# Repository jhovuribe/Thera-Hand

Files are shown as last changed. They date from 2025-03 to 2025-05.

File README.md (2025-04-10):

# Thera-Hand

## Team Members:
Jhovanny
Aliyaa
Akash
Caden
Andy
Ethan

## Need Statement
People with hand disabilities and injuries face challenges in attending
physical therapy sessions multiple times a week during their recovery period due to the demands of their lives. This will slow or reverse recovery
progress if sessions are insufficient or missed.

## Goal Statement
We aim to address this by providing a device that allows clients to perform their exercises at home, reducing in-person visits. Our goal is to make rehabilitation more convenient, accessible and efficient, allowing
clients to have more control over their recovery.

## Design Objective
We aim to reduce physical therapy visits by up to 50%, subsequently reducing insurance costs.

Team Progress Site:
https://instinctive-raft-cfa.notion.site/Project-Hub-1837bff9001a8023af18f2008f6e7fae

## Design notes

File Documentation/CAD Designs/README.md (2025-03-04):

This folder contains CAD Designs, rough drafts of certain components that will be made to accomodate our final design. Akash Srinivasan

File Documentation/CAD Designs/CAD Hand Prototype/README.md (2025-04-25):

These CAD files represent the functional prototype we will be presenting and showcasing but in CAD. We intend on using this model as a baseline for our design

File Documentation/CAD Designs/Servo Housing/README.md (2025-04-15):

This Folder contains the STEP files and CAD designs for the servo housing component included in our design

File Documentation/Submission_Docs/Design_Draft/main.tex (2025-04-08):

\documentclass{article}
\usepackage{hyperref}
\usepackage{longtable}
\usepackage{graphicx}
\usepackage{booktabs}
\usepackage{pdfpages}
\usepackage{float}
\usepackage{ragged2e}
\usepackage{placeins}
\usepackage{caption}
\usepackage{array}
\usepackage{enumitem}
\usepackage{titlesec}
\usepackage{siunitx}
\setcounter{secnumdepth}{4}
\titleformat{\paragraph}
{\normalfont\normalsize\bfseries}{\theparagraph}{1em}{}
\titlespacing*{\paragraph}
{0pt}{3.25ex plus 1ex minus .2ex}{1.5ex plus .2ex}
\title{draft_design}
\author{Caden Roberts}
\date{March 2025}

\begin{document}
\begin{titlepage}
    \centering
    \vspace*{4cm}

    % Main project title
    {\Huge \bfseries Thera-Hand\par}
    \vspace{0.75cm}

    % Subtitle
    {\LARGE \bfseries Draft Design Document\par}
    \vspace{1.5cm}

    % Course information
    {\Large CSE 123A\par}
    \vspace{0.5cm}

    % Date
    {\Large March 11, 2025\par}
    \vfill

    % Team Members
    {\large
        Akash Srinivasan \par
        Caden Roberts \par
        Jhovanny Uribe \par
        Andy Vo \par
        Ethan Cesario \par
        Aliyaa Islam \par
    }

    \vspace{1cm}
    % GitHub Link
    \href{https://github.com/jhovuribe/Physical-Therapy-Hand-Rehabilitation-Device/}{\LARGE \bfseries GitHub Repository}
    
\end{titlepage}

\section{Executive Summary}
This document details the design, development, and analysis of a hand rehabilitation device to be used in conjunction with physical therapy, titled "Thera-Hand," to improve patient adherence to therapy routines through remote monitoring and automation. The project follows a structured approach, integrating ethical considerations, user-centered design, and engineering analysis.

\section{Ethics Statement}
We reference: \href{https://www.apta.org/siteassets/pdfs/policies/codeofethicshods06-20-28-25.pdf}{The Code of Ethics for the Physical Therapist} \\ \\ 
With our physical therapy hand device we aim to address treatment for those who would
benefit from remote commitment to treatment[2][3], adapting to modern trends to benefit
therapists[6] and clients[7] and serving those without consistent access to therapy[8].
\begin{itemize}
\item Principle 2: Physical therapists shall be trustworthy and compassionate in addressing the
rights and needs of patients and clients.
\item Principle 3: Physical therapists shall be accountable for making sound professional judgments.
\item Principle 6: Physical therapists shall enhance their expertise through the lifelong acquisition
and refinement of knowledge, skills, abilities, and professional behaviors.
\item Principle 7: Physical therapists shall promote organizational behaviors and business practices
that benefit patients and clients and society.
\item Principle 8: Physical therapists shall participate in efforts to meet the health needs of people locally, nationally, or globally.
\end{itemize}

\begin{titlepage}
    \centering
    
    {\Huge \bfseries Table of Contents\par}
    \vspace{2cm}
    
    \begin{flushleft}
    {\Large \textbf{Body}} \hfill \textbf{1} \\[1cm]

    {\Large \textbf{Background}} \hfill \textbf{2} \\[0.5cm]
    \hspace{1cm} Personas \hfill \textbf{3} \\[1cm]

    {\Large \textbf{Problem Definition}} \hfill \textbf{4} \\[0.5cm]
    \hspace{1cm} Need \& Goal Statements \hfill \textbf{5} \\[0.5cm]
    \hspace{1cm} Design Objectives \hfill \textbf{6} \\[1cm]

    {\Large \textbf{Concepts Considered}} \hfill \textbf{7} \\[0.5cm]
    \hspace{1cm} Conceptualizations \hfill \textbf{8} \\[0.5cm]
    \hspace{1cm} Brain Storming Output \hfill \textbf{9} \\[1cm]

    {\Large \textbf{Concept Selection}} \hfill \textbf{10} \\[0.5cm]
    \hspace{1cm} Decision Table \hfill \textbf{11} \\[1cm]

    {\Large \textbf{Detail of Design}} \hfill \textbf{12} \\[1cm]

    {\Large \textbf{Economic Analysis}} \hfill \textbf{20} \\[0.5cm]
    \hspace{1cm} Design for Manufacture \& Assembly \hfill \textbf{21} \\[0.5cm]
    \hspace{1cm} Life Cycle Assessment \hfill \textbf{22} \\[1cm]

    {\Large \textbf{Outstanding Issues}} \hfill \textbf{25} \\[1cm]

    {\Large \textbf{Appendices}} \hfill \textbf{27} \\[0.5cm]
    \hspace{1cm} Models and Simulations \hfill \textbf{28} \\[0.5cm]
    \hspace{1cm} Decision Table Inputs \hfill \textbf{29} \\[0.5cm]
    \hspace{1cm} Test Plan \hfill \textbf{30} \\[0.5cm]
    \hspace{1cm} Test Results \hfill \textbf{31} \\[1cm]
    \end{flushleft}
    
\end{titlepage}

\section{Background}

\subsection{Personas}
\subsubsection{End User}
\begin{longtable}{|p{0.3\textwidth}|p{0.7\textwidth}|}
    \caption{User Persona: Mark} \label{table:user_persona} \\
    \hline
    \multicolumn{2}{|c|}{\textbf{End User}} \\ 
    \hline
    \endfirsthead

    \hline
    \multicolumn{2}{|c|}{\textbf{End User} (continued)} \\ 
    \hline
    \endhead

    \hline
    \multicolumn{2}{|r|}{\textit{Continued on next page}} \\ 
    \hline
    \endfoot

    \hline
    \endlastfoot

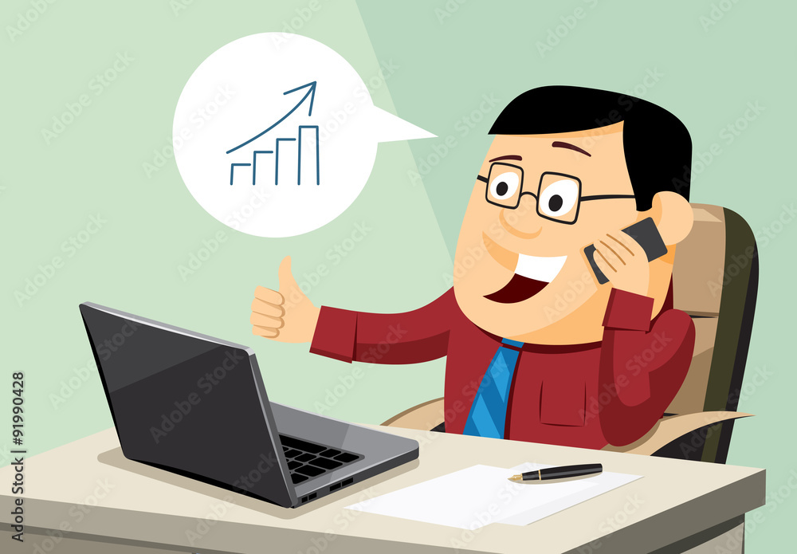
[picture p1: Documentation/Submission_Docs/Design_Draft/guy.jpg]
     & \textbf{Mark, 36 yrs old} \\ 
    \hline
    \textbf{Context} &
    \begin{itemize}
        \item Worked IT desk job for 12 years
        \item Has one kid and two cats
        \item Enjoys spending time with family
        \item Carpal tunnel syndrome caused from typing most of the day on his computer
    \end{itemize} \\
    \hline
    \textbf{Goals} &
    \begin{itemize}
        \item Wants to start stretching hands to make it better as the pain is debilitating, and he really values being active with his family and pets
    \end{itemize} \\
    \hline
    \textbf{What does this entail} &
    \begin{itemize}
        \item He struggles to do the hand exercises prescribed from his doctor as he forgets to
        \item The device will help him be consistent
    \end{itemize} \\
    \hline
\end{longtable}

\begin{longtable}{|p{0.3\textwidth}|p{0.7\textwidth}|}
    \caption{User Persona: Samantha} \label{table:user_persona_samantha} \\
    \hline
    \multicolumn{2}{|c|}{\textbf{End User}} \\ 
    \hline
    \endfirsthead

    \hline
    \multicolumn{2}{|c|}{\textbf{End User} (continued)} \\ 
    \hline
    \endhead

    \hline
    \multicolumn{2}{|r|}{\textit{Continued on next page}} \\ 
    \hline
    \endfoot

    \hline
    \endlastfoot

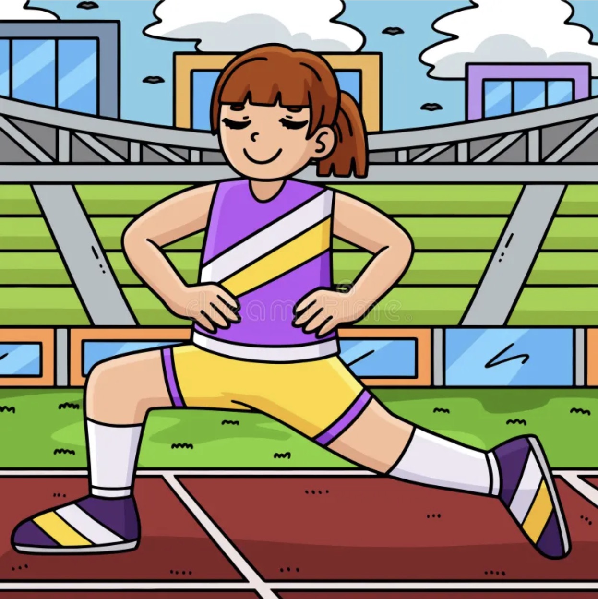
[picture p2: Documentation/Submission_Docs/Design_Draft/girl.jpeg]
     & \textbf{Samantha, 25 yrs old} \\ 
    \hline
    \textbf{Context} &
    \begin{itemize}[leftmargin=*]
        \item Weekend yoga instructor and passionate barista
        \item Enjoys hiking, taking care of her plants, and spending time with friends
        \item Got into car accident and injured hand; lost a lot of strength and mobility because of prolonged cast duration
    \end{itemize} \\
    \hline
    \textbf{Goals} &
    \begin{itemize}[leftmargin=*]
        \item Remain consistent to regain hand mobility
    \end{itemize} \\
    \hline
    \textbf{What does this entail} &
    \begin{itemize}[leftmargin=*]
        \item Struggles with progressing and sticking to physical therapy routine due to active/busy schedule
        \item Stiff/weak joints, time sensitive to regain strength and mobility
        \item Will allow her to progress without losing progress
    \end{itemize} \\
    \hline
\end{longtable}

\begin{longtable}{|p{0.3\textwidth}|p{0.7\textwidth}|}
    \caption{User Persona: Tom} \label{table:user_persona_tom} \\
    \hline
    \multicolumn{2}{|c|}{\textbf{End User}} \\ 
    \hline
    \endfirsthead

    \hline
    \multicolumn{2}{|c|}{\textbf{End User} (continued)} \\ 
    \hline
    \endhead

    \hline
    \multicolumn{2}{|r|}{\textit{Continued on next page}} \\ 
    \hline
    \endfoot

    \hline
    \endlastfoot

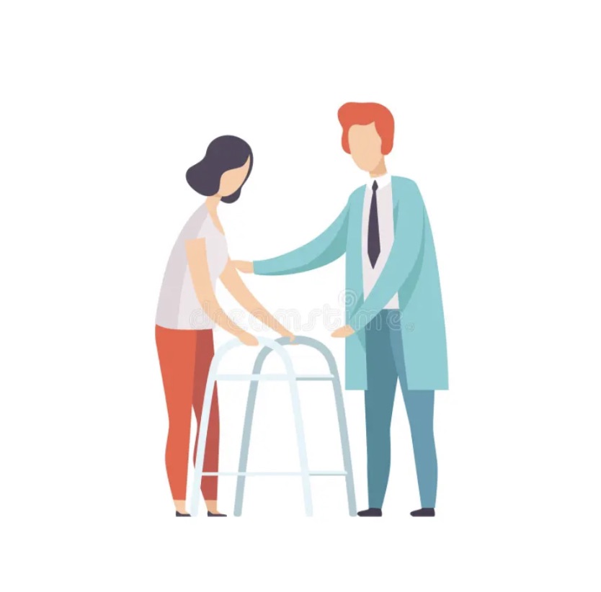
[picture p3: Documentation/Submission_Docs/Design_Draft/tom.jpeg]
     & \textbf{Tom, 42 yrs old} \\ 
    \hline
    \textbf{Context} &
    \begin{itemize}[leftmargin=*]
        \item Physical therapist 
        \item Passionate about helping his clients the best he can
    \end{itemize} \\
    \hline
    \textbf{Goals} &
    \begin{itemize}[leftmargin=*]
        \item Be able to prescribe exercises and track progress remotely with potentially stubborn clients
        \item Retain clients who otherwise would cancel therapy altogether
    \end{itemize} \\
    \hline
    \textbf{What does this entail} &
    \begin{itemize}[leftmargin=*]
        \item Understands that clients have a hard time making it to appointments and not everyone can afford to see him often
    \end{itemize} \\
    \hline
\end{longtable}

\subsubsection{Clients}

\begin{longtable}{|p{0.3\textwidth}|p{0.7\textwidth}|}
    \caption{Client: Insurance Company} \label{table:client_insurance} \\
    \hline
    \multicolumn{2}{|c|}{\textbf{Client}} \\ 
    \hline
    \endfirsthead

    \hline
    \multicolumn{2}{|c|}{\textbf{Client} (continued)} \\ 
    \hline
    \endhead

    \hline
    \multicolumn{2}{|r|}{\textit{Continued on next page}} \\ 
    \hline
    \endfoot

    \hline
    \endlastfoot

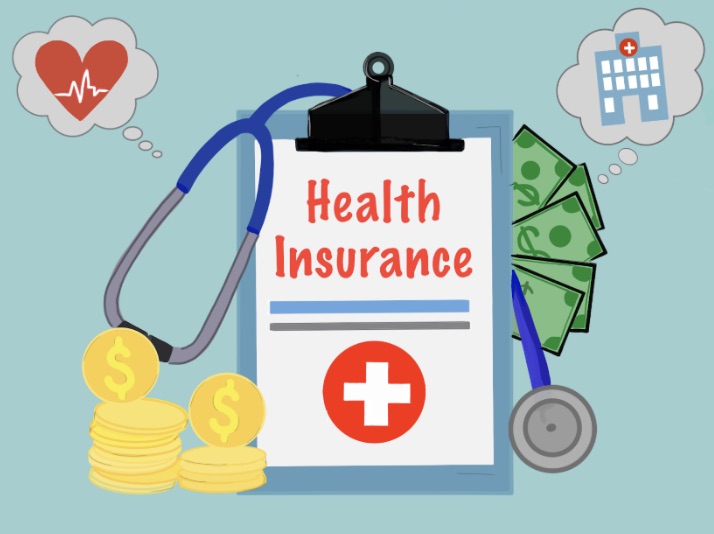
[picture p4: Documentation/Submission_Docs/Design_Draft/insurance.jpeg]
     & \textbf{Insurance Company} \\ 
    \hline
    \textbf{Context} &
    \begin{itemize}[leftmargin=*]
        \item Mid-size health insurance company 
        \item For-profit company
        \item Wants to buy product to provide a service at a cheaper price
        \item Increase retention rate for provided service
    \end{itemize} \\
    \hline
    \textbf{Goals} &
    \begin{itemize}[leftmargin=*]
        \item To provide affordable healthcare to the average person
        \item Allow more accessibility to physical therapy exercises
    \end{itemize} \\
    \hline
    \textbf{What does this entail} &
    \begin{itemize}[leftmargin=*]
        \item Replacing physical therapy visits
        \item Increasing more End Users to have access to in-person therapy meetings
    \end{itemize} \\
    \hline
\end{longtable}

\section{Problem Definition}

\subsection{Need and Goal Statements}
\subsubsection{Need Statement}
Physical therapy patients need a device that enables them to adhere to a closely monitored therapy routine.
\subsubsection{Goal Statement}
We want to create a device that enables routine monitoring of therapy adherence for physical therapy patients.

\subsection{Design Objectives}
Design a cost-effective solution that is user-friendly and streamlines the rehabilitation process.
\begin{longtable}{|l|l|l|}
    \caption{Design Objectives and Targets} \label{tab:design_objectives} \\
    \hline
    \textbf{Design Objective} & \textbf{Unit} & \textbf{Target/Range} \\ \hline
    \endfirsthead

    \hline
    \textbf{Design Objective} & \textbf{Unit} & \textbf{Target/Range} \\ \hline
    \endhead

    \hline
    \multicolumn{3}{|r|}{\textit{Continued on next page}} \\ \hline
    \endfoot

    \hline
    \endlastfoot

    Visits & Number of visits & 10\%--50\% less \\ \hline
    Device Cost & Dollars & \textgreater{} \$1440 \\ \hline
    Accessibility & Minutes & Greater than session time \\ \hline
    Weight & lbs & \ \textless{} 2 lbs \\ \hline
    % Add more rows as needed
\end{longtable}
\section{Concepts Considered}
\subsection{Brainstorm}
\includepdf[pages=-]{brainstorm.pdf}
\subsection{6-3-5 Method}
\includepdf[pages=-]{635_Designs.pdf}
\subsection{Morphological Chart}
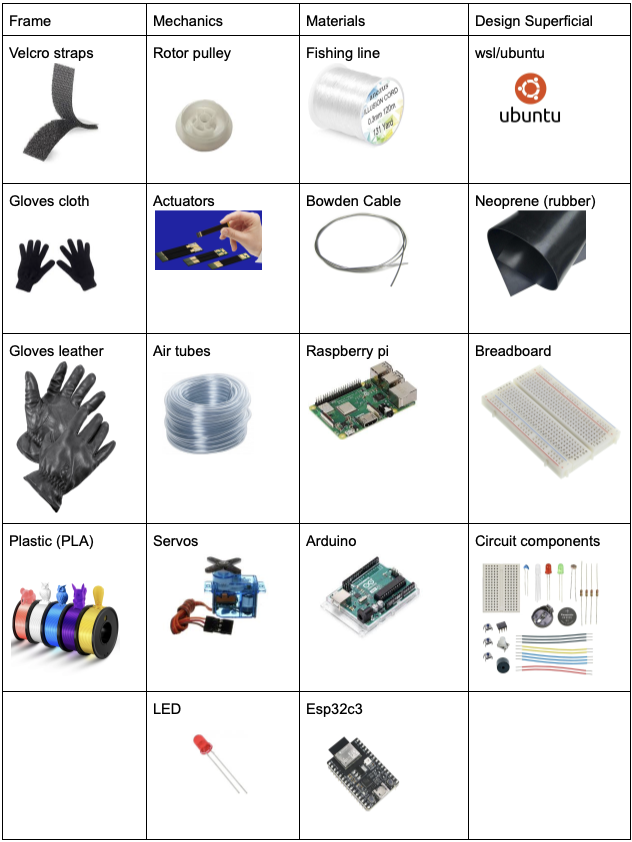
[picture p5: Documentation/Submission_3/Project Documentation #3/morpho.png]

\subsection{Mind Map}
\includepdf[pages=-]{Mindmap.pdf}

\section{Concept Selection}

\subsection{Decision Table}
\begin{table}[h]
    \noindent\hspace{-4.5cm}
    \small
    \begin{tabular}{l c | c c | c c | c c}
        \toprule
        \textbf{Criteria} & \textbf{Weight (\%)} & \multicolumn{2}{c|}{\textbf{Design 1 (Attached Fingers)}} & \multicolumn{2}{c|}{\textbf{Design 2 (Prosthetic Hand)}} & \multicolumn{2}{c}{\textbf{Design 3 (Pneumatic)}} \\
        \cmidrule(lr){3-4} \cmidrule(lr){5-6} \cmidrule(lr){7-8}
        & & Raw & Weighted & Raw & Weighted & Raw & Weighted \\
        \midrule
        Wearability (person) & 20 & 8 & 160 & 7 & 140 & 7 & 140 \\
        Cost & 30 & 9 & 270 & 6 & 180 & 3 & 90 \\
        Damage Likelihood (device) & 10 & 8 & 80 & 6 & 60 & 5 & 50 \\
        Power Consumption & 5 & 10 & 50 & 8 & 40 & 6 & 30 \\
        Weight & 15 & 9 & 135 & 5 & 75 & 4 & 60 \\
        Functionality & 20 & 6 & 120 & 9 & 180 & 10 & 200 \\
        \midrule
        \textbf{Total} & & & 815 & & 675 & & 570 \\
        \bottomrule
    \end{tabular}
\end{table}

\section{Detail of Design}
Majority of Document

\subsection{Free format description of design}
Include diagrams, schematics, wire-frames, etc.
Be reasonably detailed but remember this is not yet complete

\section{Economic Analysis}

\subsection{Design for Manufacture and Assembly}

\subsection{Life Cycle Assessment}
\subsubsection{Goal and Scope Definition}
\paragraph{Objective}
The LCA aims to assess the environmental footprint of the Thera-Hand rehabilitation device, considering its:
\begin{itemize}
\item Energy consumption (power supply, servos, ESP32).
\item Material usage (PLA, rubber, fishing line, sensors).
\item Manufacturing and transportation impact.
\item End-of-life disposal/recycling feasibility.
\end{itemize}
\paragraph{Functional Unit}
A single Thera-Hand device is assumed to be used for 2 years before replacement.
\paragraph{System Boundaries}
This LCA includes:
\begin{itemize}
\item Raw Material Extraction – Plastics, rubber, and electronics production.
\item Manufacturing and Assembly – 3D printing, PCB production, servo motor production.
\item Transportation – From manufacturing to users.
\item Use Phase – Power consumption during operation.
\item End of Life – Disposal, recycling, or potential reuse.
\end{itemize}
\subsubsection{Inventory Analysis}
\paragraph{Material Composition and Impact}
\begin{table}[h]
    \hspace*{-3.5cm}
    \centering
    \begin{tabular}{|l|l|l|}
        \hline
        \textbf{Component} & \textbf{Material} & \textbf{Environmental Impact} \\ 
        \hline
        Frame \& Housing & PLA (3D printed) & Low-carbon footprint, biodegradable under specific conditions \\ 
        \hline
        Sensors & Flexible PCB, resistive materials & Electronic waste, difficult to recycle \\ 
        \hline
        Actuators (Servos) & Plastic, copper wiring & High-energy manufacturing, limited recyclability \\ 
        \hline
        Power Supply & Electronic components, metal & Requires responsible e-waste disposal \\ 
        \hline
        Wiring \& Fishing Line & Copper wiring, nylon & Small footprint, but non-biodegradable \\ 
        \hline
    \end{tabular}
    \label{tab:material_composition}
\end{table}
\paragraph{Energy Consumption(Use Phase)}
Based on prior power consumption estimates:
\begin{table}[h]
    \hspace*{-2.2cm}
    \centering
    \begin{tabular}{|l|c|c|c|}
        \hline
        \textbf{Component} & \textbf{Power Consumption (W)} & \textbf{Usage per day (hours)} & \textbf{Annual Energy (kWh)} \\ 
        \hline
        ESP32 & 1.25W & 2 & 0.91 kWh \\ 
        \hline
        5 SG90 Servos & 6.25W (idle) / 16.25W (peak) & 1 & 5.93 kWh \\ 
        \hline
        Sensors \& LED & 0.15W & 2 & 0.11 kWh \\ 
        \hline
        \textbf{Total Estimate} & $\approx$ 7.65W - 17.65W & - & 6-7 kWh/year \\ 
        \hline
    \end{tabular}
    \caption{Comparison: This is equivalent to a low-power LED bulb running for ~3 months.}
    \label{tab:energy_consumption}
\end{table}
\subsubsection{Impact Assessment (Environmental)}
\paragraph{Manufacturing:}
\begin{itemize}
\item Electronics production (ESP32, sensors, servos) has the highest carbon footprint.
\item 3D printing (PLA) requires energy but has a relatively low impact compared to metals.
\end{itemize}
\paragraph{Use Phase:}
\begin{itemize}
\item Low electricity consumption (~6-7 kWh/year) makes it energy-efficient.
\end{itemize}
\paragraph{End-of-Life Considerations:}
\begin{itemize}
\item PLA parts are biodegradable in industrial composting but not in landfills.
\item Servos, wiring, and PCBs require responsible e-waste recycling.
\end{itemize}
\subsubsection{Interpretation and Recommendations}
\paragraph{Key Findings}
\begin{itemize}
    \item Low Energy Consumption: Thera-Hand is energy-efficient in use.
    \item Minimal Carbon Footprint for PLA: The frame is eco-friendly, but plastics must be disposed
of properly.
    \item E-Waste Challenge: Sensors, servos, and the ESP32 must be recycled properly.
    \item Transportation Impact: If shipped globally, the CO$_2$ footprint increases.
\end{itemize}
\paragraph{Recommendations}
\begin{itemize}
    \item Optimize 3D Printing Material: Use recycled PLA or biodegradable TPU to reduce waste.
    \item E-Waste Collection Plan: Offer a recycling take-back program for electronics.
    \item Reduce Servo Impact: Use low-power or energy-efficient servos if possible.
    \item Sustainable Packaging: Use biodegradable or recycled materials for packaging.
\end{itemize}

\subsubsection{Conclusion}
\begin{itemize}
\item Thera-Hand is a low-energy, partially sustainable device.
\item The biggest environmental concern is e-waste disposal of sensors and servos.
\item Efforts to recycle electronic components and use sustainable materials can improve its
eco-friendliness.
\end{itemize}

\section{Outstanding Issues}

\subsection{Models and Simulations}

\includepdf[pages=-]{sketch-merged.pdf}
\includepdf[pages=-]{Assembly_therahand.png}

\subsection{Decision Table Inputs}

\begin{table}[h]
    \centering
    \begin{tabular}{l c}
        \toprule
        \textbf{Criteria} & \textbf{Weight (\%)} \\
        \midrule
        Wearability & 20 \\
        Cost & 30 \\
        Damage Likelihood & 10 \\
        Power Consumption & 5 \\
        Weight & 15 \\
        Functionality & 20 \\
        \bottomrule
    \end{tabular}
\end{table}

\subsection{Test Plan}
\subsubsection{Ability to be turned on/off}
The device should have the ability to be turned off separately from being unplugged.

\paragraph{Goal} The device should be able to be turned on and off while still connected to a direct power source.

\paragraph{External Factors} Make sure the power connection is stable and not under loaded.

\paragraph{Equipment} Hand device with external bank, Power Source.

\paragraph{Steps}
\begin{enumerate}
\item The device should not be connected to any person.
\item The device should be connected to an AC stable power supply of at least 120 Volts. A common wall socket is preferred.
\item Load any basic exercise and wait more than 10 seconds.
\item Turn off the device by pressing the power button on the box connected to the wall. Make sure to press the power button before the exercise has ended.
\item Observe and measure the time it takes the device to stop moving.
\item Repeat steps 3-5 multiple times with different exercises.
\end{enumerate}

\subsubsection{Ability to download/save metrics}
Data should be stored and sent remotely after each exercise is completed.

\paragraph{Goal} The device should be able to remotely send data to an external device that can store data.

\paragraph{External Factors} Unstable power supply, unstable internet connection, and connectivity issues.

\paragraph{Equipment} Hand device with external bank, Power Source, Separate device connected to the Internet and connected to the device.

\paragraph{Steps}
\begin{enumerate}
\item Plug the device into a stable 120 Volts AC power supply, preferably a wall outlet.
\item Load the exercise onto the device and begin the workout. Preferably a short workout routine.
\item Connect the therapist's device to a stable internet connection.
\item Pair the device to a therapist's computer, allowing it to download and store the device's workout data.
\item Start the workout and wait for it to finish.
\item Observe the download of the device.
\end{enumerate}

\subsubsection{Weight}
Determine the weight of the device that is on the hand. Under two pounds.

\paragraph{Goal} The device should weigh less than 2 pounds or 1 kilogram.

\paragraph{External Factors} The scale should be accurate enough to detect under five pounds and should be zeroed before use.

\paragraph{Equipment} Hand device without external bank, small scale.

\paragraph{Steps}
\begin{enumerate}
\item Unplug the device from the power bank and computer.
\item Place the device on the scale. The glove should be dry and empty. Strings should be attached from servos to the fingers.
\end{enumerate}

\subsubsection{Accuracy of repetition counting}
The device should be tested to report as many repetitions as are being performed. We need to know the degree of error of our data.

\paragraph{Goal} The device should count the repetitions performed ideally with perfect accuracy.

\paragraph{External factors} The device should be properly calibrated to recognize when a full range of motion repetition has occurred.

\paragraph{Equipment} Hand device with external bank, Power Source, Separate device connected to the internet and connected to the device.

\paragraph{Steps}
\begin{enumerate}
\item Plug the device into a 120 Volt AC outlet.
\item Turn the device on and begin a basic squeezing exercise, beginning with fingers outstretched, then fully contracting all fingers to the center of the palm (must touch to be counted as a rep), and finally outstretch all fingers again.
\item While the device records repetitions, manually count how many repetitions occur until the time is over.
\item Compare the number of repetitions the device reports to the number of repetitions observed.
\end{enumerate}

\subsubsection{Individual controllability}
Each finger should be able to operate independently of any other finger.

\paragraph{Goal} Verify that each finger is independently programmable and movable.

\paragraph{External factors} Individual anatomy and flexibility of those being tested.

\paragraph{Equipment} Hand device with external bank, Power Source, Separate device connected to the internet and connected to the device.

\paragraph{Steps}
\begin{enumerate}
\item Plug the device into a 120 Volt AC outlet.
\item First, turn the device on and verify that each finger can be pulled in individually.
\item Lastly, check that each finger can individually be extended back out.
\end{enumerate}

\subsubsection{Resting state}
The device should return to a resting state after the completion of each exercise.

\paragraph{Goal} The device should be verified to return to a neutral state after each exercise is completed.

\paragraph{External factors} Someone’s anatomy or flexibility may prevent a typical “neutral” resting state.

\paragraph{Equipment} Hand device with external bank, Power Source, Separate device connected to the internet and connected to the device.

\paragraph{Steps}
\begin{enumerate}
\item Plug the device into a 120V AC outlet.
\item Turn the device on and begin a basic squeezing exercise, beginning with fingers outstretched, then fully contracting all fingers to the center of the palm (must touch to be counted as a rep), and finally outstretch all fingers again.
\item After completion of the exercise, verify that the device has returned to its neutral resting state.
\end{enumerate}

\subsubsection{Full Range of Motion on each finger}
The device should be able to move in the full range of motion for each finger. Determine through flex sensor data in the amount of flexion (degrees).

\paragraph{Goal} The device should demonstrate flexion within the expected biomechanical range (0-90 for DIP, 0-100 for PIP, 0-90 for MCP, depending on finger). Deviation beyond 2.5\% of standard human range to be flagged for recalibration. If the device does not meet the expected range, adjustments in control algorithms and mechanical design may be necessary.

\paragraph{External factors} Ambient temperature variations, Device vibrations and mechanical inconsistencies, Any potential latency in response times.

\paragraph{Equipment} Glove with integrated flex sensors, Voltage divider circuit with known resistor (\si{\ohm}), Arduino, Computer for data logging and visualization.

\paragraph{Steps}
\begin{enumerate}
    \item Mount the device securely and ensure proper calibration of flex sensors.
    \item Record natural rest position of each finger.
    \item Actuate each finger from full extension to full flexion.
    \item Record flex sensor data at key points of movement (0, 45, 90, etc.).
    \item Repeat the process for each finger, ensuring consistency.
\end{enumerate}

\subsubsection{Ability to fit on a common hand}
The device should be able to fit securely and comfortably on common hand sizes, using straps for adjustability.

\paragraph{Goal} The device should securely fit common hand sizes without excessive gaps or pressure points. The adjustable straps should allow for a customized fit without discomfort. If fit issues arise, modifications to strap length, padding, or buckle placement may be necessary.

\paragraph{External factors} Impact of movement on strap security. Any noticeable discomfort due to prolonged wear.

\paragraph{Equipment} Robotic/assistive hand device with straps for adjustability. 3D hand model (male/female). Measuring tools for assessing gaps and pressure points (ruler, measuring tape, etc.). User feedback for qualitative comfortability assessment.

\paragraph{Steps}
\begin{enumerate}
    \item Prepare the hand models and device with adjustable straps. Ensure straps are at their default adjustment before each trial.
    \item Measure the circumference of each hand model at the middle of the hand and forearm.
    \item Place the device on each hand model and secure it using the straps. Adjust the straps for a snug but comfortable fit.
    \item Record strap tension using measuring tape and pressure sensors.
    \item Conduct subjective assessment for comfort and stability.
\end{enumerate}

\subsubsection{Durability of the device}

\paragraph{Goal} The device should maintain functional integrity for at least 100,000 flexion cycles without significant degradation. The structural components should withstand typical impact forces without catastrophic failure. Environmental exposure should not lead to material breakdown or loss of functionality. If durability issues arise, material selection, mechanical design, or protective coatings may need revision.

\paragraph{External factors} Effects of prolonged use on mechanical performance. Environmental factors leading to premature material failure.

\paragraph{Equipment} Robotic/assistive hand device. Mechanical testing rig for repeated flexion cycles. Load cell sensors to measure stress and strain. Environmental chamber for temperature and humidity variations. Impact testing apparatus for drop and shock resistance.

\paragraph{Steps}
\begin{enumerate}
    \item Mount the device on a mechanical testing rig.
    \item Calibrate sensors to measure force, stress, and performance degradation.
    \item Record initial material integrity and functionality metrics.
    \item Subject each finger mechanism to repeated flexion cycles (minimum 100,000 cycles).
    \item Monitor for signs of wear, stiffness, or failure.
    \item Drop the device from various heights onto different surfaces. 
    \item Assess structural damage and continued operability.
    \item Expose the device to temperature fluctuations (-10 Celsius to 50 Celsius) and high humidity.
    \item Evaluate material degradation and operational stability.
\end{enumerate}

\subsection{Test Results}

\begin{table}[H]
    \hspace*{-1 cm}
    \centering
    \begin{tabular}{|c|c|p{8cm}|}
        \hline
        \textbf{Name(s)} & \textbf{Date/Location} & \textbf{Tests} \\
        \hline
        & & \textbf{Test 1:} Did the power turn off? (Yes/No) \\
        \hline
        & & \textbf{Test 2:} Was data remotely sent? (Yes/No) \\
        \hline
        & & \textbf{Test 3:} Weight: (kg/lbs) \\ 
        \hline
        & & \textbf{Test 4:} What accuracy were the repetitions counted to? (\%) \\
        \hline
        & & \textbf{Test 5:} How many fingers were individually controllable? (0-5) \\
        \hline
        & & \textbf{Test 6:} Did the device return to a resting state? (Yes/No) \\
        \hline
        & & \textbf{Test 7:} Full Range of Motion on each finger? (Yes/No) \\
        \hline
        & & \textbf{Test 8:} Ability to fit on common hand? (Yes/No) \\
        \hline
        & & \textbf{Test 9:} Device Durability acceptable? (Yes/No) \\
        \hline
    \end{tabular}
    \caption{Test Log}
    \label{tab:test_log}
\end{table}

\end{document}

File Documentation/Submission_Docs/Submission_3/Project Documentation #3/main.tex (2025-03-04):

\documentclass{article}
\usepackage{hyperref}
\usepackage{graphicx} % Required for inserting images
\usepackage{booktabs}
\usepackage{pdfpages}
\usepackage{float}
\title{submission_3}
\author{Caden Roberts}
\date{March 2025}

\begin{document}
\begin{titlepage}
    \centering
    \vfill
    {\Huge \bfseries Project Documentation 3\par}
    \vspace{1.5cm}
    {\Huge
        Akash Srinivasan \par \ \par
        Caden Roberts \par \ \par
        Jhovanny Uribe \par \ \par
        Andy Vo \par \ \par
        Ethan Cesario \par \ \par
        Aliyaa Islam \par \ \par
    }
    \vspace{1cm}
    {\Huge \bfseries Mar 3 2025\par}
    \vspace{1.5cm}
    \href{https://github.com/jhovuribe/Physical-Therapy-Hand-Rehabilitation-Device/}{\Huge \bfseries Github}
\end{titlepage}

\section{Design for Manufacture and Assembly}
\includepdf[pages=-]{sketch-merged.pdf}
\section{Ethics Statement}
We reference: \href{https://www.apta.org/siteassets/pdfs/policies/codeofethicshods06-20-28-25.pdf}{The Code of Ethics for the Physical Therapist} \\ \\ 
With our physical therapy hand device we aim to address treatment for those who would
benefit from remote commitment to treatment[2][3], adapting to modern trends to benefit
therapists[6] and clients[7] and serving those without consistent access to therapy[8].
\begin{itemize}
\item Principle 2: Physical therapists shall be trustworthy and compassionate in addressing the
rights and needs of patients and clients.
\item Principle 3: Physical therapists shall be accountable for making sound professional judgments.
\item Principle 6: Physical therapists shall enhance their expertise through the lifelong acquisition
and refinement of knowledge, skills, abilities, and professional behaviors.
\item Principle 7: Physical therapists shall promote organizational behaviors and business practices
that benefit patients and clients and society.
\item Principle 8: Physical therapists shall participate in efforts to meet the health needs of people locally, nationally, or globally.
\end{itemize}

\section{Budget for Prototype}

\begin{table}[h]
    \hspace*{-2.2cm}
    \centering
    \begin{tabular}{|l|c|l|c|c|}
        \hline
        \textbf{Item} & \textbf{Quantity} & \textbf{Vendor} & \textbf{Price per Unit (\$)} & \textbf{Total Cost (\$)} \\ 
        \hline
        Flex Sensors & 5 & [Spectra Symbol] & 10.85 & 54.25 \\ 
        \hline
        Microcontroller (ESP32) & 1 & [AITRIP] & 15.99 & 15.99 \\ 
        \hline
        Glove & 1 & [LYDTICK] & 16.99 & 16.99 \\ 
        \hline
        Wiring \& Connectors & 1 (pack) & [Spark Fun] & 5.97 & 5.97 \\ 
        \hline
        Battery Pack & 1 & [Raion Group] & 29.95 & 29.95 \\ 
        \hline
        3D Print Filament & 1 & [AMOLEN] & 29.99 & 29.99 \\ 
        \hline
        Actuator (Micro-Servos) & 1 (10 pack) & [Smraza] & 18.99 & 18.99 \\ 
        \hline
        Server Cost (Monthly) & N/A & [AWS] & Free Tier & Free \\ 
        \hline
        Velcro & 1 & [ULINE] & 20.00 & 20.00 \\ 
        \hline
        \textbf{TOTAL} & & & & \textbf{192.13} \\ 
        \hline
    \end{tabular}
    \label{tab:cost}
\end{table}
\section{Life Cycle Assessment}
\subsection{Goal and Scope Definition}
\subsubsection{Objective}
The LCA aims to assess the environmental footprint of the Thera-Hand rehabilitation device, considering its:
\begin{itemize}
\item Energy consumption (power supply, servos, ESP32).
\item Material usage (PLA, rubber, fishing line, sensors).
\item Manufacturing and transportation impact.
\item End-of-life disposal/recycling feasibility.
\end{itemize}
\subsubsection{Functional Unit}
A single Thera-Hand device is assumed to be used for 2 years before replacement.
\subsubsection{System Boundaries}
This LCA includes:
\begin{itemize}
\item Raw Material Extraction – Plastics, rubber, and electronics production.
\item Manufacturing and Assembly – 3D printing, PCB production, servo motor production.
\item Transportation – From manufacturing to users.
\item Use Phase – Power consumption during operation.
\item End of Life – Disposal, recycling, or potential reuse.
\end{itemize}
\subsection{Inventory Analysis}
\subsubsection{Material Composition and Impact}
\begin{table}[h]
    \hspace*{-3.5cm}
    \centering
    \begin{tabular}{|l|l|l|}
        \hline
        \textbf{Component} & \textbf{Material} & \textbf{Environmental Impact} \\ 
        \hline
        Frame \& Housing & PLA (3D printed) & Low-carbon footprint, biodegradable under specific conditions \\ 
        \hline
        Sensors & Flexible PCB, resistive materials & Electronic waste, difficult to recycle \\ 
        \hline
        Actuators (Servos) & Plastic, copper wiring & High-energy manufacturing, limited recyclability \\ 
        \hline
        Power Supply & Electronic components, metal & Requires responsible e-waste disposal \\ 
        \hline
        Wiring \& Fishing Line & Copper wiring, nylon & Small footprint, but non-biodegradable \\ 
        \hline
    \end{tabular}
    \label{tab:material_composition}
\end{table}
\subsubsection{Energy Consumption(Use Phase)}
Based on prior power consumption estimates:
\begin{table}[h]
    \hspace*{-2.2cm}
    \centering
    \begin{tabular}{|l|c|c|c|}
        \hline
        \textbf{Component} & \textbf{Power Consumption (W)} & \textbf{Usage per day (hours)} & \textbf{Annual Energy (kWh)} \\ 
        \hline
        ESP32 & 1.25W & 2 & 0.91 kWh \\ 
        \hline
        5 SG90 Servos & 6.25W (idle) / 16.25W (peak) & 1 & 5.93 kWh \\ 
        \hline
        Sensors \& LED & 0.15W & 2 & 0.11 kWh \\ 
        \hline
        \textbf{Total Estimate} & $\approx$ 7.65W - 17.65W & - & 6-7 kWh/year \\ 
        \hline
    \end{tabular}
    \caption{Comparison: This is equivalent to a low-power LED bulb running for ~3 months.}
    \label{tab:energy_consumption}
\end{table}
\subsection{Impact Assessment (Environmental)}
\subsubsection{Manufacturing:}
\begin{itemize}
\item Electronics production (ESP32, sensors, servos) has the highest carbon footprint.
\item 3D printing (PLA) requires energy but has a relatively low impact compared to metals.
\end{itemize}
\subsubsection{Use Phase:}
\begin{itemize}
\item Low electricity consumption (~6-7 kWh/year) makes it energy-efficient.
\end{itemize}
\subsubsection{End-of-Life Considerations:}
\begin{itemize}
\item PLA parts are biodegradable in industrial composting but not in landfills.
\item Servos, wiring, and PCBs require responsible e-waste recycling.
\end{itemize}
\subsection{Interpretation and Recommendations}
\subsubsection{Key Findings}
\begin{itemize}
    \item Low Energy Consumption: Thera-Hand is energy-efficient in use.
    \item Minimal Carbon Footprint for PLA: The frame is eco-friendly, but plastics must be disposed
of properly.
    \item E-Waste Challenge: Sensors, servos, and the ESP32 must be recycled properly.
    \item Transportation Impact: If shipped globally, the CO$_2$ footprint increases.
\end{itemize}
\subsubsection{Recommendations}
\begin{itemize}
    \item Optimize 3D Printing Material: Use recycled PLA or biodegradable TPU to reduce waste.
    \item E-Waste Collection Plan: Offer a recycling take-back program for electronics.
    \item Reduce Servo Impact: Use low-power or energy-efficient servos if possible.
    \item Sustainable Packaging: Use biodegradable or recycled materials for packaging.
\end{itemize}

\subsection{Conclusion}
\begin{itemize}
\item Thera-Hand is a low-energy, partially sustainable device.
\item The biggest environmental concern is e-waste disposal of sensors and servos.
\item Efforts to recycle electronic components and use sustainable materials can improve its
eco-friendliness.
\end{itemize}
\section{Test Plan}

\subsection{Ability to be turned on/off}
The device should have the ability to be turned off separately from being unplugged.
\subsubsection{Goal} The Device should be able to be turned on and off while still connected to a direct power source.
\subsubsection{External Factors} Make sure the power connection is stable and not underloaded.
\subsubsection{Equipment} Hand device with external bank, Power Source.
\subsubsection{Steps}
\begin{enumerate}
\item The device should not be connected to any person.
\item The device should be plugged into an AC stable power supply of at least 120V. A
common wall socket is preferred.
\item Load any basic exercise and wait longer than 10 seconds.
\item Turn off the device by pressing the power button on the box connected to the wall. Make
sure to press the power button before the exercise has finished.
\item Observe and measure the time it takes for the device to stop movement.
\item Repeat steps 3-5 multiple times with differing exercises.
\end{enumerate}
\subsection{Ability to download/save metrics}
Data should be stored and sent remotely after each exercise is completed.
\subsubsection{Goal} The Device should be able to remotely send data to an external device that can store
data.
\subsubsection{External Factors} Unstable power supply, unstable internet connection, and connectivity issues.
\subsubsection{Equipment} Hand device with external bank, Power Source, Separate device connected to
internet and connected to device.
\subsubsection{Steps}
\begin{enumerate}
\item Plug the device into a stable 120V AC power supply, preferably a wall outlet.
\item Load the exercise onto the device and begin the workout. Preferably a short workout
routine.
\item Connect the therapist's device to a stable internet connection.
\item Pair the device to a therapist's computer, allowing it to download and store the device's
workout data.
\item Start the workout and wait for it to finish.
\item Observe the download of the device
\end{enumerate}
\subsection{Weight}
Determine the weight of the device that is worn on the hand. Under two pounds.
\subsubsection{Goal} The device should weigh under 2 lbs or 1kg.
\subsubsection{External Factors} The scale should be accurate enough to detect under five pounds and should
be zeroed before use.
\subsubsection{Equipment} Hand device without external bank, small scale.
\subsubsection{Steps}
\begin{enumerate}
\item Unplug the device from the power bank and computer.
\item Place the device on the scale. The glove should be dry and empty. Strings should be attached from servos to fingers.
\end{enumerate}
\subsection{Accuracy of repetition counting}
The device should be tested to report as many repetitions as are being performed. We need to know the degree of error of our data.
\subsubsection{Goal} The device should count the repetitions performed ideally with perfect accuracy.
\subsubsection{External factors} The device should be properly calibrated to recognize when a full range of motion repetition has occurred.
\subsubsection{Equipment} Hand device with external bank, Power Source, Separate device connected to the internet and connected to the device.
\subsubsection{Steps}
\begin{enumerate}
\item Plug the device into a 120V AC outlet.
\item Turn the device on and begin basic squeeze exercises, where fingertips must touch, for 10 seconds.
\item While the device records repetitions, manually count how many repetitions occur until the time is over.
\item Compare the number of repetitions the device reports to the number of repetitions observed.
\end{enumerate}
\subsection{Individual controllability} Each finger should be able to operate independently of any other finger.
\subsubsection{Goal} Verify that each finger is independently programmable and movable.
\subsubsection{External factors} Individual anatomy and flexibility of those being tested.
\subsubsection{Equipment} Hand device with external bank, Power Source, Separate device connected to the internet and connected to the device.
\subsubsection{Steps}
\begin{enumerate}
\item Plug the device into a 120V AC outlet.
\item Turn the device on and verify each finger individually can be pulled in individually.
\item Verify each finger individually can be extended back out.
\end{enumerate}
\subsection{Resting state}
The device should return to a resting state after the completion of each exercise.
\subsubsection{Goal} The device should be verified to return to a neutral state after each exercise is completed.
\subsubsection{External factors} Someone’s anatomy or flexibility may prevent a typical “neutral” resting state.
\subsubsection{Equipment} Hand device with external bank, Power Source, Separate device connected to the internet and connected to the device.
\subsubsection{Steps}
\begin{enumerate}
\item Plug the device into a 120V AC outlet.
\item Turn the device on and begin an exercise.
\item After completion of the exercise, verify that the device has returned to its neutral resting state.
\end{enumerate}
\subsection{Full Range of Motion on each finger}
The device should be able to move in the full range of
motion for each finger. Determine through flex sensor data in the amount of flexion (degrees).
\subsubsection{Goal} The device should demonstrate flexion within the expected biomechanical range (0-90 for DIP, 0-100 for PIP, 0-90 for MCP, depending on finger). Deviation beyond 2.5\% of standard human range to be flagged for recalibration. If the device does not meet the expected range, adjustments in control algorithms and
mechanical design may be necessary.
\subsubsection{External factors}
Ambient temperature variations, Device vibrations and mechanical inconsistencies, Any potential latency in response times.
\subsubsection{Equipment}
Glove with integrated flex sensors, Voltage divider circuit with known resistor (? ohms), Arduino, Computer for data logging and visualization
\subsubsection{Steps}
\begin{enumerate}
    \item Mount the device securely and ensure proper calibration of flex sensors.
    \item Record natural rest position of each finger.
    \item Actuate each finger from full extension to full flexion.
    \item Record flex sensor data at key points of movement (0, 45, 90, etc.).
    \item Repeat the process for each finger, ensuring consistency.
\end{enumerate}

\subsection{Ability to fit on a common hand}
The device should be able to fit securely and comfortably on common hand sizes, using straps for adjust-ability.
\subsubsection{Goal} The device should securely fit common hand sizes without excessive gaps or pressure
points. The adjustable straps should allow for a customized fit without discomfort. If fit issues arise, modifications to strap length, padding, or buckle placement may be
necessary.
\subsubsection{External factors}
Impact of movement on strap security. Any noticeable discomfort due to prolonged wear.
\subsubsection{Equipment}
Robotic/assistive hand device with straps for adjustability. 3D hand model (male/female). Measuring tools for assessing gaps and pressure points (ruler, measuring tape, etc.). User feedback for qualitative comfortability assessment.
\subsubsection{Steps}
\begin{enumerate}
    \item Prepare the hand models and device with adjustable straps. Ensure straps are at their default adjustment before each trial.
    \item Measure the circumference of each hand model at the middle of the hand and forearm.
    \item Place the device on each hand model and secure it using the straps. Adjust the straps for a snug but comfortable fit.
    \item Record strap tension using measuring tape and pressure sensors.
    \item Conduct subjective assessment for comfort and stability.
\end{enumerate}

\subsection{Durability of the device}
\subsubsection{Goal} The device should maintain functional integrity for at least 100,000 flexion cycles without significant degradation. The structural components should withstand typical impact forces without catastrophic failure. Environmental exposure should not lead to material breakdown or loss of functionality. If durability issues arise, material selection, mechanical design, or protective coatings may need revision.
\subsubsection{External factors}
Effects of prolonged use on mechanical performance. Environmental factors leading to premature material failure.
\subsubsection{Equipment}
Robotic/assistive hand device. Mechanical testing rig for repeated flexion cycles. Load cell sensors to measure stress and strain. Environmental chamber for temperature and humidity variations. Impact testing apparatus for drop and shock resistance.
\subsubsection{Steps}
\begin{enumerate}
    \item Mount the device on a mechanical testing rig.
    \item Calibrate sensors to measure force, stress, and performance degradation.
    \item Record initial material integrity and functionality metrics.
    \item Subject each finger mechanism to repeated flexion cycles (minimum 100,000 cycles).
    \item Monitor for signs of wear, stiffness, or failure.
    \item Drop the device from various heights onto different surfaces. 
    \item Assess structural damage and continued operability.
    \item Expose the device to temperature fluctuations (-10C to 50C) and high humidity.
    \item Evaluate material degradation and operational stability.
\end{enumerate}

\begin{table}[H]
    \hspace*{-1cm}
    \centering
    \begin{tabular}{|c|c|}
        \hline
        \textbf{Name(s)} & \textbf{Date and Location} \\
        \hline
        \ & \ \\
        \hline
        \textbf{Test 1:} Did the power turn off? (Yes/No) & \\
        \hline
        \textbf{Test 2:} Was data remotely sent? (Yes/No) & \\
        \hline
        \textbf{Test 3:} Weight: (kg/lbs) & \\ 
        \hline
        \textbf{Test 4:} What accuracy were the repetitions counted to? (\%) & \\
        \hline
        \textbf{Test 5:} How many fingers were individually controllable? (0-5) & \\
        \hline
        \textbf{Test 6:} Did the device return to a resting state? (Yes/No) & \\
        \hline
        \textbf{Test 7:} Full Range of Motion on each finger? (Yes/No) & \\
        \hline
        \textbf{Test 8:} Ability to fit on
        common hand? (Yes/No) & \\
        \hline
        \textbf{Test 9:} Device
        Durability acceptable? (Yes/No) & \\
        \hline
    \end{tabular}
    \caption{Test Log}
    \label{tab:test_log}
\end{table}

\section{Updates}
\subsection{Need Statement}
Physical therapy for hand rehabilitation is a time- and cost-intensive process with limited at-home alternative options; providing an easy-to-produce and cheap-to-manufacture device
\subsection{Goal Statement}
We aim to reduce physical therapy visits by up to 50\%, subsequently reducing insurance costs by designing a cost-effective device.
\subsection{Design Objective}
Design a cost-effective solution that is user-friendly and streamlines the rehabilitation process.
\subsection{Morphological Chart}

\subsection{Gantt Chart}
\href{https://docs.google.com/spreadsheets/d/12JjnpXyDDq8c87AdqVN5jQ46xVcHvgcuxsZTP0hWSw0/edit?usp=sharing}{Link to Updated Gantt Chart}
\newline
\newline
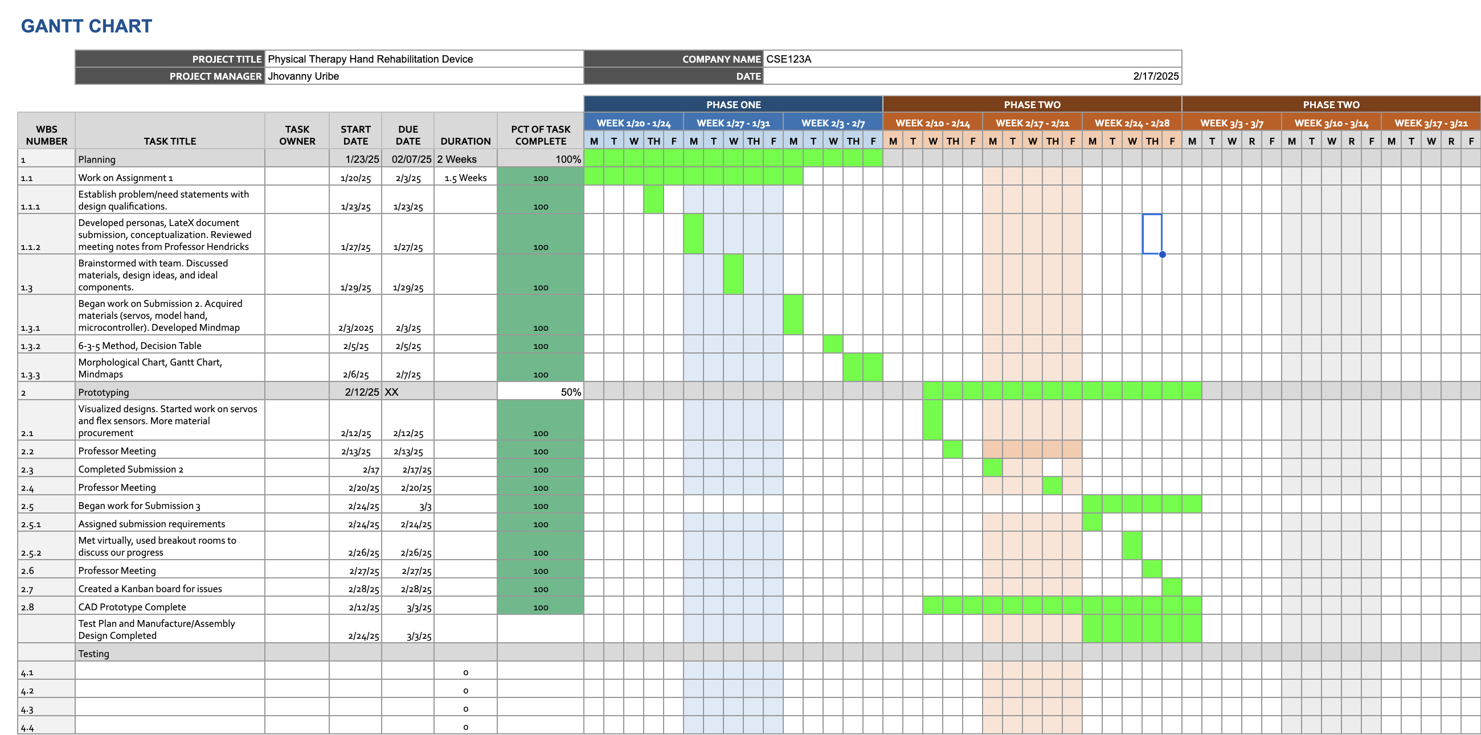
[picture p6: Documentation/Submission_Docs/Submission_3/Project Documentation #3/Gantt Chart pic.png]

\end{document}

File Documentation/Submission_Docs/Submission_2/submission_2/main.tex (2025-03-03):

\documentclass{article}
\usepackage{booktabs}
\usepackage{graphicx} % Required for inserting images
\usepackage{longtable}
\usepackage{pdfpages}
\usepackage{float}
\usepackage{booktabs}
\usepackage{multirow}
\restylefloat{table}
\begin{document}
\begin{titlepage}
    \centering
    \vfill
    {\Huge \bfseries Project Documentation 2\par}
    \vspace{1.5cm}
    {\Huge
        Akash Srinivasan \par \ \par
        Caden Roberts \par \ \par
        Jhovanny Uribe \par \ \par
        Andy Vo \par \ \par
        Ethan Cesario \par \ \par
        Aliyaa Islam \par \ \par
    }
    \vspace{1.5cm}
    {\Huge \bfseries February 17 2025\par}
\end{titlepage}
\section{Conceptualizations}
\subsection{Brainstorming}
\includepdf[pages=-]{brainstorm.pdf}
\subsection{6-3-5 Method}
\includepdf[pages=-]{635_Designs.pdf}
\subsection{Morphological Chart}
\begin{table}[h]
    \hspace*{-1.5cm}
    \centering
    \begin{tabular}{|c|c|c|c|c|}
        \hline
        \textbf{Velcro Straps} & \textbf{WSL/Ubuntu} & \textbf{Wooden Hand} & \textbf{Fishing Line} & \textbf{Rotor Pulley} \\
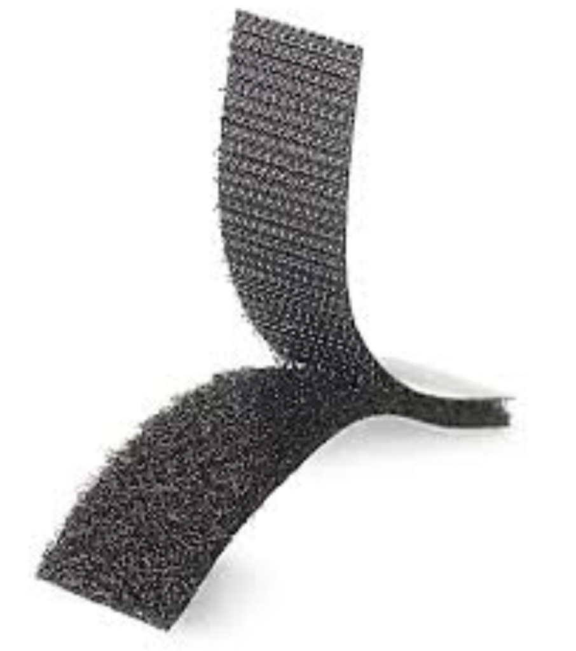
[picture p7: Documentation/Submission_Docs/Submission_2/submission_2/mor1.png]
         & 
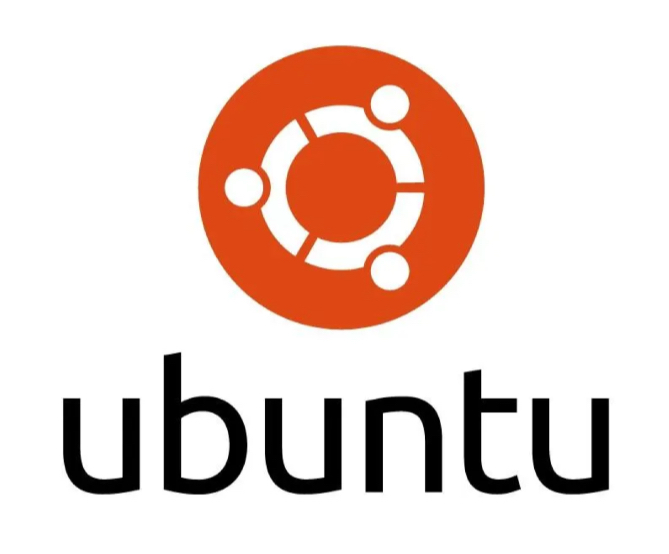
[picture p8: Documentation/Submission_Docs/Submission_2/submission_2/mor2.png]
         & 
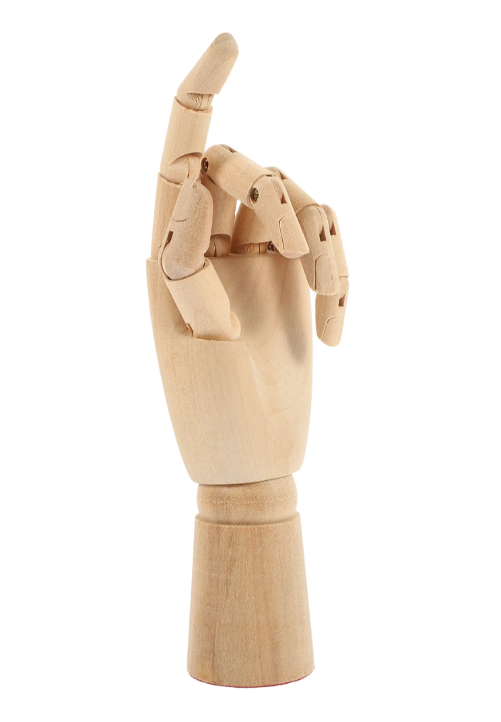
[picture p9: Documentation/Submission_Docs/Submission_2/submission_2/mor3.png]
         & 
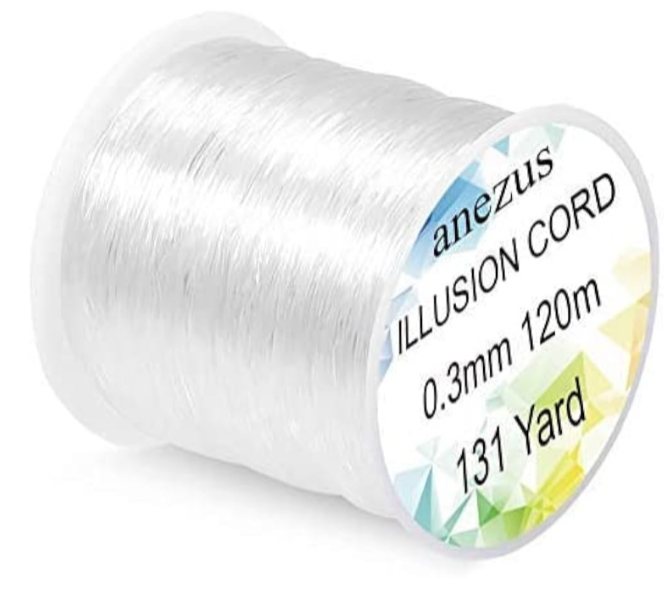
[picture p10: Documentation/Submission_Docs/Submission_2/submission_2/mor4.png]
         & 
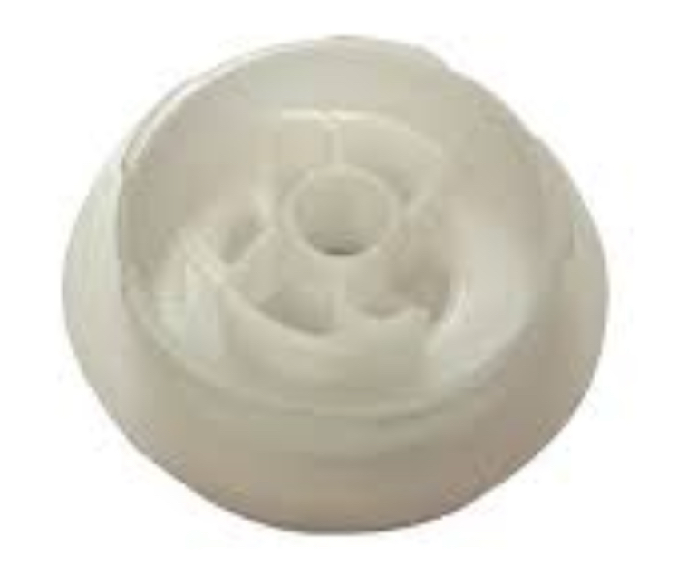
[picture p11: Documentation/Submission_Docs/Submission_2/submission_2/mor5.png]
         \\
        \hline
        \textbf{Gloves} & \textbf{Raspberry Pi} & \textbf{Silicone Hand} & \textbf{Bowden Cable} & \textbf{Air Tubes} \\
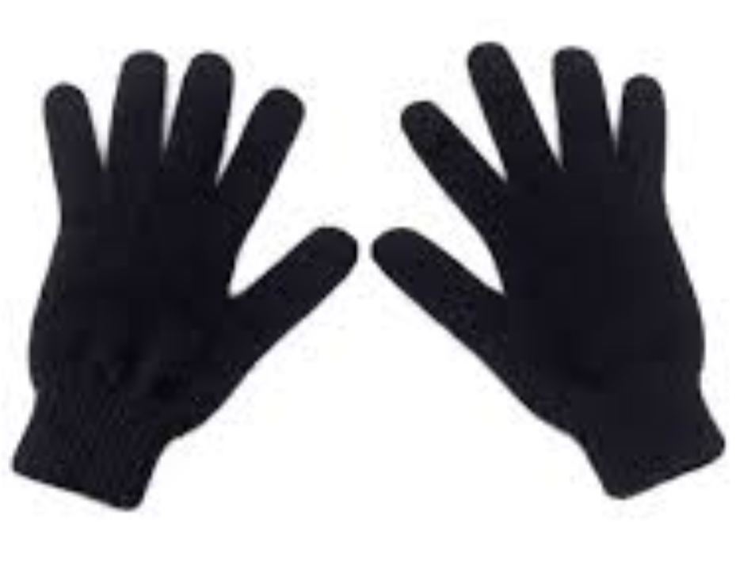
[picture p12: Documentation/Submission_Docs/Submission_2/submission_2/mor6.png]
         & 
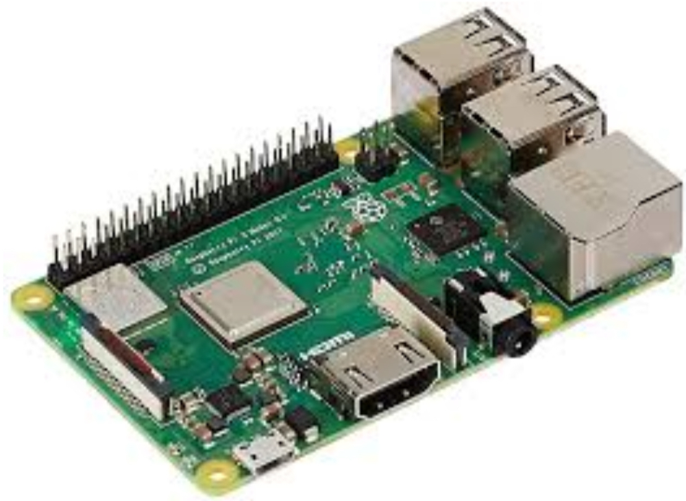
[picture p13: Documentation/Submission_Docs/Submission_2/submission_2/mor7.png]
         & 
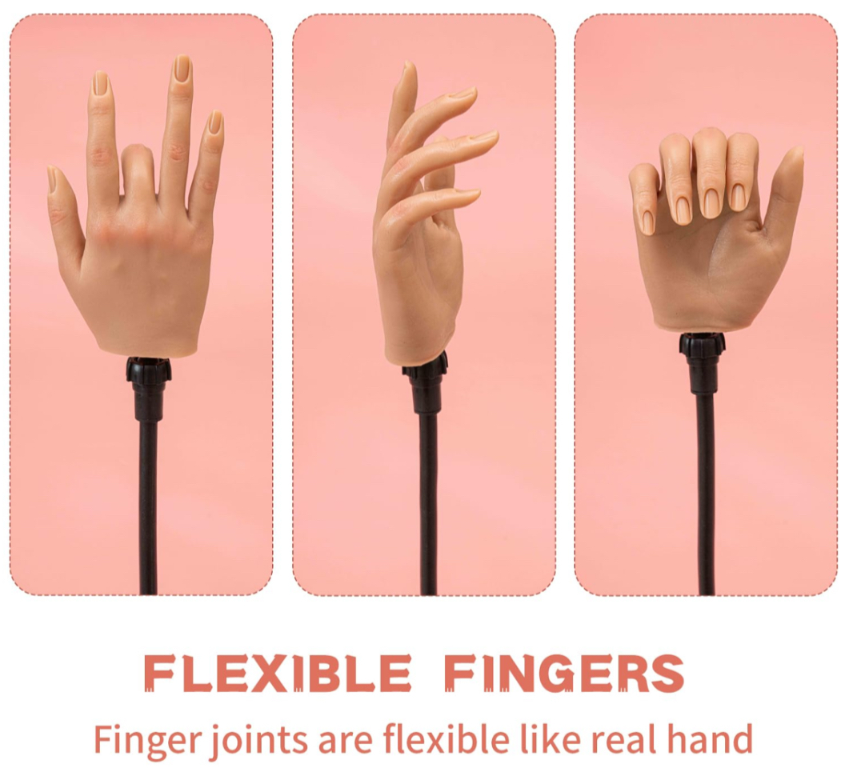
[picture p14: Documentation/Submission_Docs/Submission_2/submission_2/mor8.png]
         & 
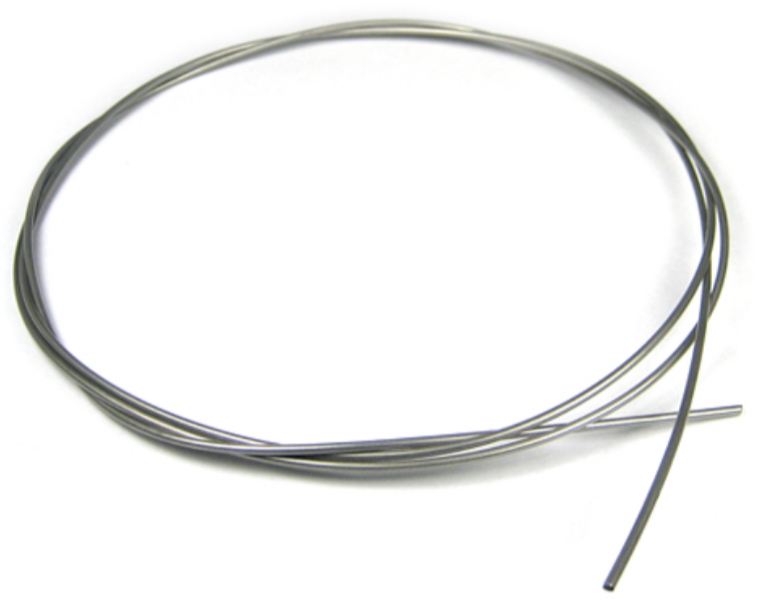
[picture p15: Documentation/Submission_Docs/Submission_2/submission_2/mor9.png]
         & 
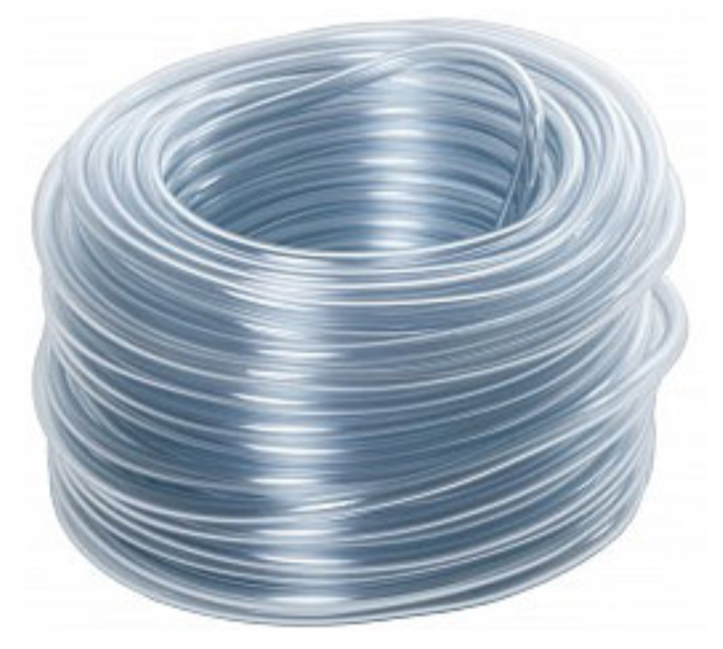
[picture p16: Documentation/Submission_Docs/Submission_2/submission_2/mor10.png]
         \\
        \hline
        \textbf{Hot Glue Gun} & \textbf{ESP32-C3} & & & \textbf{Plastic (PLA)} \\
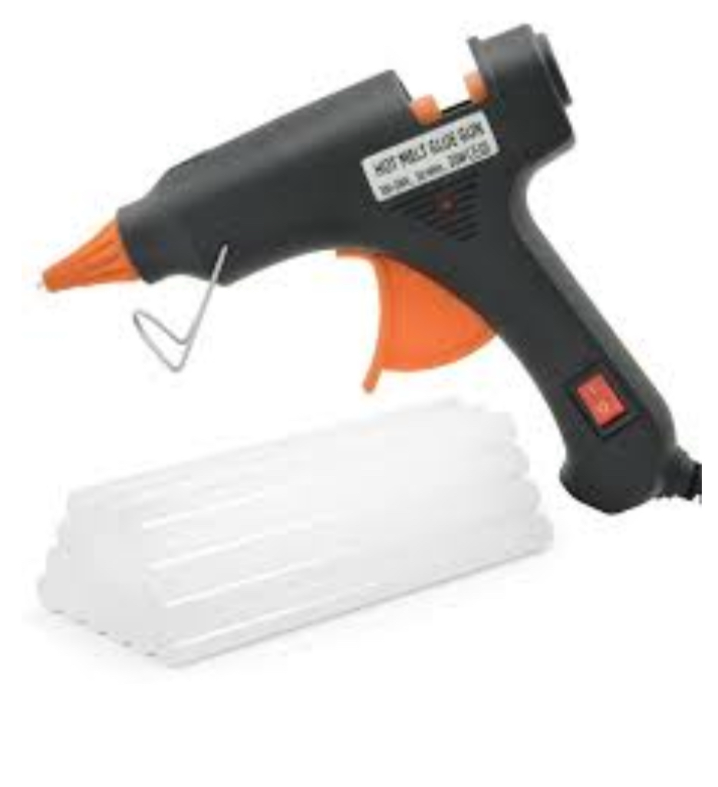
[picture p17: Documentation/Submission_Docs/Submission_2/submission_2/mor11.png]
         & 
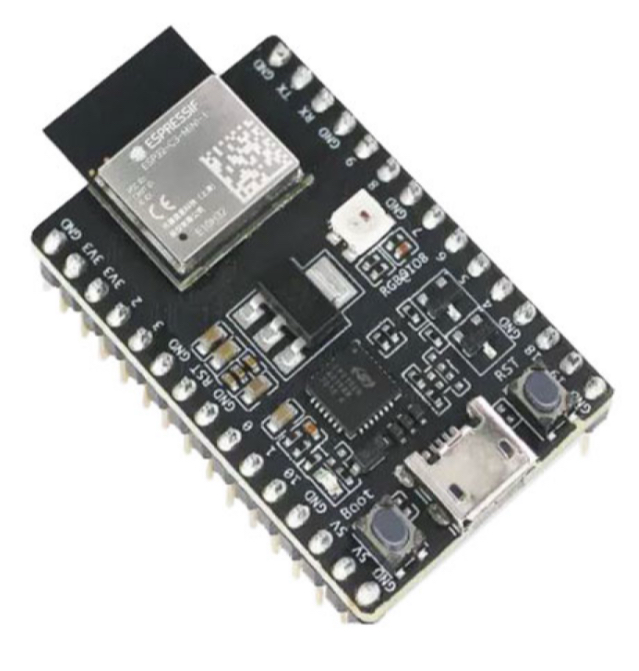
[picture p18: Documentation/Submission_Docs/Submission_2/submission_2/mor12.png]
         & 
        & 
        & 
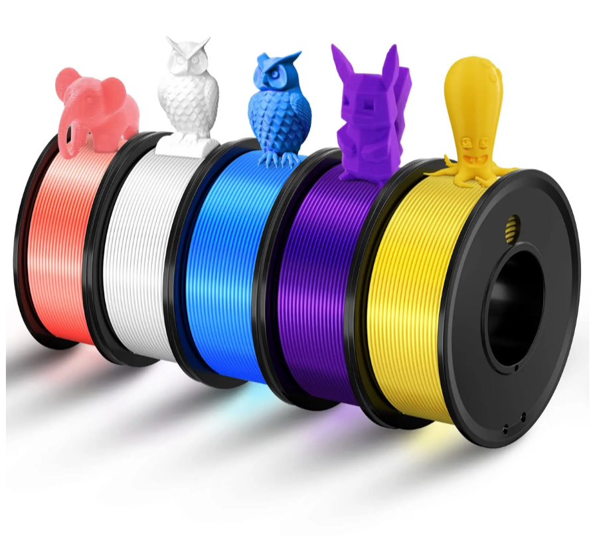
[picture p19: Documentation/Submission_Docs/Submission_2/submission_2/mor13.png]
         \\
        \hline
        & \textbf{Arduino} & & & \textbf{Actuators} \\
        & 
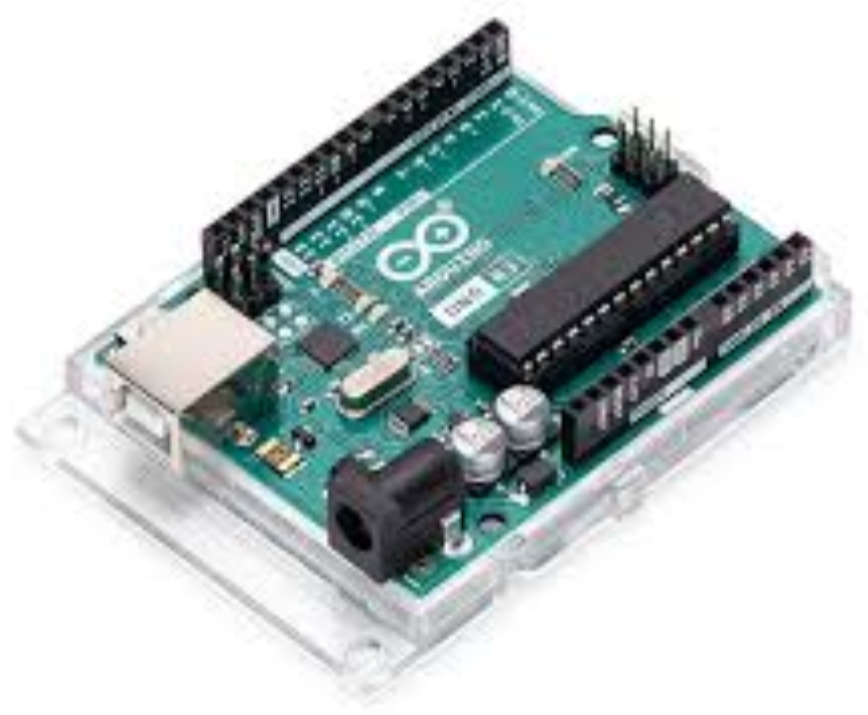
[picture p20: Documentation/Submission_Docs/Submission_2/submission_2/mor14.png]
         & 
        & 
        & 
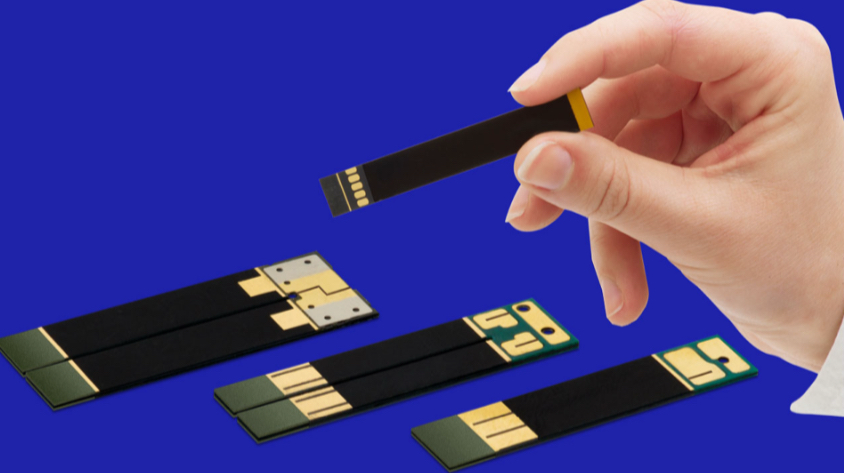
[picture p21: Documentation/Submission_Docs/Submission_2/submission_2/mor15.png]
         \\
        \hline
        & & & & \textbf{Neoprene (Rubber)} \\
        & & & & 
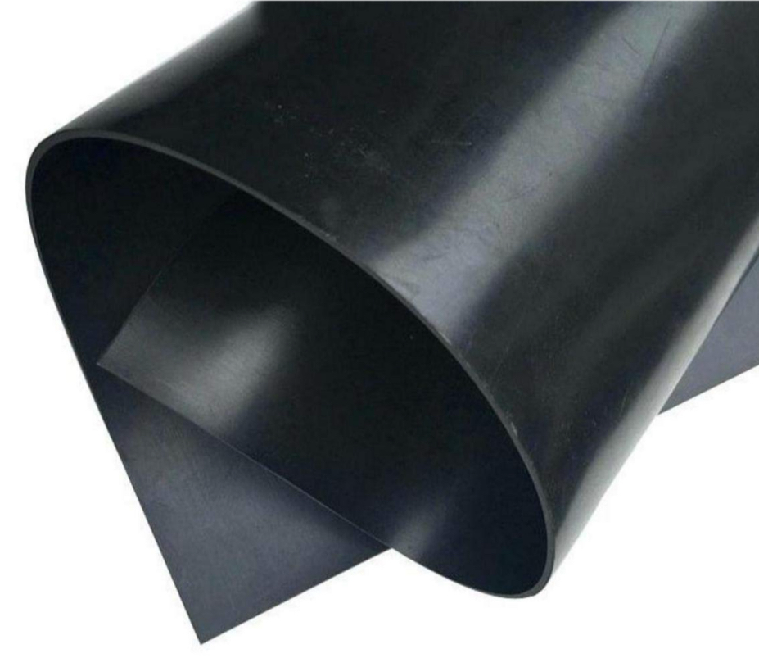
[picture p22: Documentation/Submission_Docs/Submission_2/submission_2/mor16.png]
         \\
        \hline
    \end{tabular}
\end{table}

\subsection{Mind Map}
\includepdf[pages=-]{Mindmap.pdf}

\subsection{Decision Tables}

\begin{table}[h]
    \noindent\hspace{-4.5cm}
    \small
    \begin{tabular}{l c | c c | c c | c c}
        \toprule
        \textbf{Criteria} & \textbf{Weight (\%)} & \multicolumn{2}{c|}{\textbf{Design 1 (Attached Fingers)}} & \multicolumn{2}{c|}{\textbf{Design 2 (Prosthetic Hand)}} & \multicolumn{2}{c}{\textbf{Design 3 (Pneumatic)}} \\
        \cmidrule(lr){3-4} \cmidrule(lr){5-6} \cmidrule(lr){7-8}
        & & Raw & Weighted & Raw & Weighted & Raw & Weighted \\
        \midrule
        Wearability (person) & 20 & 8 & 160 & 7 & 140 & 7 & 140 \\
        Cost & 30 & 9 & 270 & 6 & 180 & 3 & 90 \\
        Damage Likelihood (device) & 10 & 8 & 80 & 6 & 60 & 5 & 50 \\
        Power Consumption & 5 & 10 & 50 & 8 & 40 & 6 & 30 \\
        Weight & 15 & 9 & 135 & 5 & 75 & 4 & 60 \\
        Functionality & 20 & 6 & 120 & 9 & 180 & 10 & 200 \\
        \midrule
        \textbf{Total} & & & 815 & & 675 & & 570 \\
        \bottomrule
    \end{tabular}
\end{table}

\begin{table}[h]
    \centering
    \begin{tabular}{l c}
        \toprule
        \textbf{Criteria} & \textbf{Weight (\%)} \\
        \midrule
        Wearability & 20 \\
        Cost & 30 \\
        Damage Likelihood & 10 \\
        Power Consumption & 5 \\
        Maintenance & 15 \\
        Weight & 20 \\
        \bottomrule
    \end{tabular}
\end{table}

\subsection{Gantt Chart}

\begin{table}[h]
    \centering
    \small
    \makebox[\textwidth]{ 
    \hspace{2cm} 
    \begin{tabular}{|l|l|l|l|c|}
        \toprule
        \textbf{WBS Number} & \textbf{Task Title} & \textbf{Start Date} & \textbf{Due Date} & \textbf{Completion (\%)} \\
        \midrule
        1 & Planning & 01/23/25 & 02/07/25 & 100\% \\
        1.1 & Work on Assignment 1 & 01/23/25 & 02/03/25 & 100\% \\
        1.1.1 & Establish problem/need statements & 01/23/25 & 01/23/25 & 100\% \\
        1.1.2 & Develop personas, LaTeX document & 01/27/25 & 01/27/25 & 100\% \\
        1.3 & Brainstorm design ideas & 01/29/25 & 01/29/25 & 100\% \\
        1.3.1 & Submission 2, Acquired materials & 02/03/25 & 02/03/25 & 100\% \\
        1.3.2 & 6-3-5 Method, Decision Table & 02/05/25 & 02/05/25 & 100\% \\
        1.3.3 & Morphological Chart, Gantt Chart, Mindmaps & 02/10/25 & 02/10/25 & 100\% \\
        \hline 
        2 & Prototyping & 02/12/25 & XX & 5\% \\
        2.1 & CAD designs, 3D printed objects, flex sensors & 02/12/25 & 02/12/25 & 100\% \\
        2.2 & TBD & - & - & 0\% \\
        \hline 
        3 & Testing & - & - & 0\% \\
        \hline 
        4 & Refinement & - & - & 0\% \\
        \midrule
        \bottomrule
    \end{tabular}
    }
    \caption{Gantt Chart Table}
\end{table}

\end{document}

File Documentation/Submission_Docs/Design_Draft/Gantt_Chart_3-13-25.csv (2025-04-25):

GANTT CHART |  |  |  |  |  |  |  |  |  |  |  |  |  |  |  |  |  |  |  |  |  |  |  |  |  |  |  | https://goo.gl/PXLbMe
 | PROJECT TITLE | Physical Therapy Hand Rehabilitation Device |  |  |  |  | COMPANY NAME |  |  |  |  |  |  |  |  | CSE123A
 | PROJECT MANAGER | Jhovanny Uribe |  |  |  |  | DATE |  |  |  |  |  |  |  |  | 2/17/2025
 |  |  |  |  |  |  | PHASE ONE |  |  |  |  |  |  |  |  |  |  |  |  |  |  | PHASE TWO |  |  |  |  |  |  |  |  |  |  |  |  |  |  | PHASE TWO |  |  |  |  |  |  |  |  |  |  |  |  |  |  | PHASE THREE
WBS NUMBER | TASK TITLE | TASK OWNER | START DATE | DUE DATE | DURATION | PCT OF TASK COMPLETE | WEEK 1/20 - 1/24 |  |  |  |  | WEEK 1/27 - 1/31 |  |  |  |  | WEEK 2/3 - 2/7 |  |  |  |  | WEEK 2/10 - 2/14 |  |  |  |  | WEEK 2/17 - 2/21 |  |  |  |  | WEEK 2/24 - 2/28 |  |  |  |  | WEEK 3/3 - 3/7 |  |  |  |  | WEEK 3/10 - 3/14 |  |  |  |  | WEEK 3/17 - 3/21 |  |  |  |  | WEEK 10 |  |  |  |  | WEEK 11
 |  |  |  |  |  |  | M | T | W | TH | F | M | T | W | TH | F | M | T | W | TH | F | M | T | W | TH | F | M | T | W | TH | F | M | T | W | TH | F | M | T | W | R | F | M | T | W | R | F | M | T | W | R | F | M | T | W | R | F | M | T
1 | Planning |  | 1/23/25 | 02/07/25 | 2 Weeks | 100%
1.1 | Work on Assignment 1 |  | 1/20/25 | 2/3/25 | 1.5 Weeks | 100
1.1.1 | Establish problem/need statements with design qualifications. |  | 1/23/25 | 1/23/25 |  | 100
1.1.2 | Developed personas, LateX document submission, conceptualization. Reviewed meeting notes from Professor Hendricks |  | 1/27/25 | 1/27/25 |  | 100
1.3 | Brainstormed with team. Discussed materials, design ideas, and ideal components. |  | 1/29/25 | 1/29/25 |  | 100
1.3.1 | Began work on Submission 2. Acquired materials (servos, model hand, microcontroller). Developed Mindmap |  | 2/3/2025 | 2/3/25 |  | 100
1.3.2 | 6-3-5 Method, Decision Table |  | 2/5/25 | 2/5/25 |  | 100
1.3.3 | Morphological Chart, Gantt Chart, Mindmaps |  | 2/6/25 | 2/7/25 |  | 100
2 | Prototyping |  | 2/12/25 | XX |  | 50%
2.1 | Visualized designs. Started work on servos and flex sensors. More material procurement |  | 2/12/25 | 2/12/25 |  | 100
2.2 | Professor Meeting |  | 2/13/25 | 2/13/25 |  | 100
2.3 | Completed Submission 2 |  | 2/17 | 2/17/25 |  | 100
2.4 | Professor Meeting |  | 2/20/25 | 2/20/25 |  | 100
2.5 | Began work for Submission 3 |  | 2/24/25 | 3/3 |  | 100
2.5.1 | Assigned submission requirements |  | 2/24/25 | 2/24/25 |  | 100
2.5.2 | Met virtually, used breakout rooms to discuss our progress |  | 2/26/25 | 2/26/25 |  | 100
2.6 | Professor Meeting |  | 2/27/25 | 2/27/25 |  | 100
2.7 | Created a Kanban board for issues |  | 2/28/25 | 2/28/25 |  | 100
2.8 | CAD Prototyping |  | 2/12/25 | 3/3/25 |  | 100
 | Test Plan and Manufacture/Assembly Design |  | 2/24/25 | 3/3/25
 | Professor Meeting |  | 3/6/25 | 3/6/25
4.1 | Design Document |  | 3/7/25 | 3/13/2025
4.2 | Interim Presentation |  | 3/7/25 | 3/13/25 | 6
4.3 |  |  |  |  | 0
4.4 |  |  |  |  | 0
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

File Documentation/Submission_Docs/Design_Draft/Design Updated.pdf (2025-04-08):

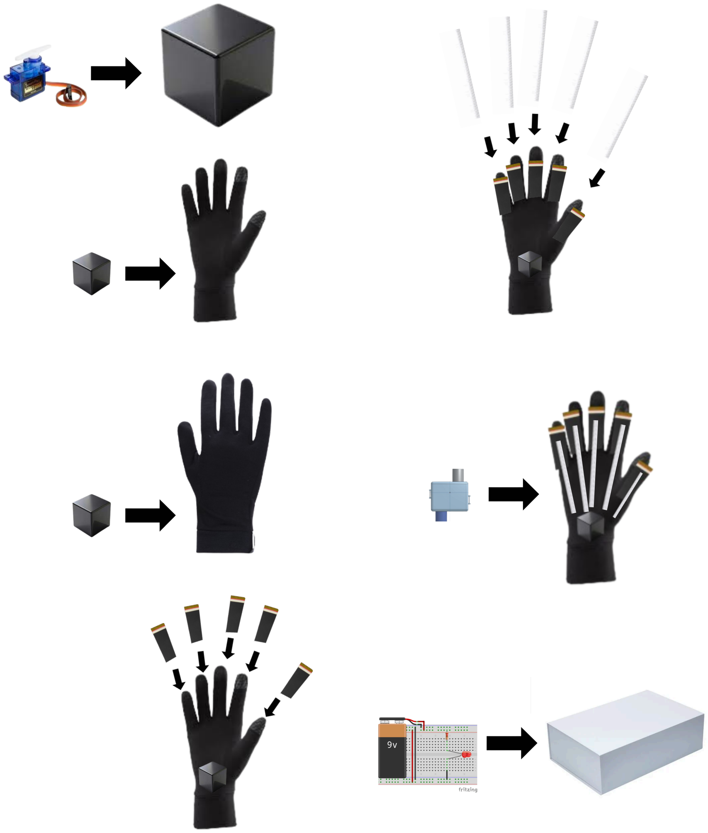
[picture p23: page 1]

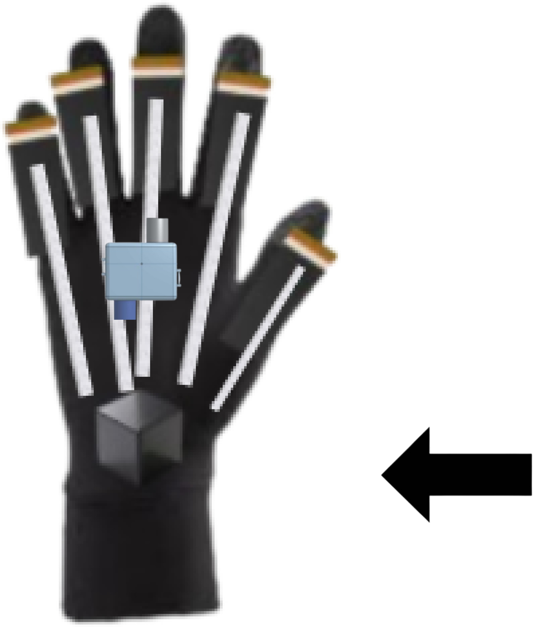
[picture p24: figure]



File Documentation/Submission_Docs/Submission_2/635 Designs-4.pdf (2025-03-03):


L

# rt----~ J\A,1,_\ ~~ ~ ~'J\O_ Ci\ l c1 \w- ~ LL~-==

l:>~-5- lS_ "'--~aa-,L !-"'tJ,f ~..ul)\.,vt-<. ~ _ 11&1r;hl ~t1--- r-- ~J~ .. ,~~ ~ n...J.f- ~i / ~ O'~ c.,.A.A,t'[.c ___ ~ - .

### t-_ ___ .- ~ -~us Jt.uJ -~ Y!Uf_ -~f- 1D __ '64:J~_,._1'tr~ (_~b01ft-r-

----- ~ ~1k. ~ ~ - o<,f ~ 0 Sf_1 __d r{~-~-t ?__

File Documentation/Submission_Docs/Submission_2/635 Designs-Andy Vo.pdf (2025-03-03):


~- - 11~\-ui °"-\ ~rw--0i eds ro
b-t 5 O-.ri ~ ~ CAncl V\J) \---1
,' .W °'-.S "X,d

/ --+·' -----

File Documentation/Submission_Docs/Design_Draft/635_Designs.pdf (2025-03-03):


r

t

J h~ flfl.d
ur,"te,
- 1 ~\{,, tl'Q_G~t,,<'.J_( _ | ____ +-,-,f----===--~~--=- | ----
- - ~V~h-9-0-J-6,____b_t~- - | --1· | ------

## 1 ~rn pJ;cJ~ I Prvt>i ™---r. -~=-----

## 1 vot-t~_;_ ----- ----=-- -:-_ _;~ _=-:: -""'-~~u\\\&-~~tUtt~\C."\

- Coultl AAl-r -- | -- ------- V -~ -fi:.rrca lll\i\"'-t0-\()A \-o - | - | '1cl I | - --
~n-::i~ i~i~~ ,_ &t<'lZ- -h~] -- -_ ---ft~=Cri;\at- -""~-t_.__~ ~ | ~~;\{, -- __ LJ _ - --- | -VttiMl ieVVA~-J.uke _ | v | ~ | -
, ws.~ :-\~ | --.A<l" \----+-->-- | ,., - " - | -pvrr-c~r~ ;.t - - | - -- --
U:V\J~-tc \f~ | ----°;--z,~::_r~- ~ --; | -
-\ffi\f'\ | . ·-. . vi V'-t'\ | (' | ;t~ ---- (,: 50cc, r~-,-tr~ ,- Jv!'~~~~~-a- | -- - | -

ir--r ~o~~ t')._e),HGi ~(Y\-°"

~~ _ ll5g-"ttfle_AA1 C,~- | -- | --------
-_ _ -\---o °"-~ yf ~ | cK_ c)r\~~e\ | -fo-1 1lt, h,vlce 1~ | ~ | \ | ft1' SGC\() '? --~ | c,~Y\~~ JJ:,__l_\_~--°"-r.:ts- to_ _ ~ )(, ~~lfjrJ..~i'A\1 6, | ______ _
- ~ | ~1n~u-11~e1f_ _ | _ leiv-;c.e, __ . __ _

### -----t-1 ______ - --- -----

----t--1 - | -------- | -------


--,.--!...\..l,.l.u1Lm-ro0.lli~ k t1~~- 'w •, tf\ \ ~\ e., x_ ~()\J e, | oJ hov$eS Wl'/--
----.µ,A.C}.[Jfuoo oJ h o.v-c) wo.r(,,- | P\c~L b.e..nut::i½ th_e,,~!_ ____ _ __
" | • \ \ VI t1-f.~~\)u~~_1in¥N---------------
, | ~hll~~ O "--~~\_~-&J:n~ ~JL.,\A\~_ti'_\,~to | -
-~\\\ t ~\\ \l\ \~U\~~\· | Utt\'~G\1\\LS ~ l \\t\Q.. \~\'}.\},t~
~ \'\ ~ '-- \~').~\, | tN\\\~l ~\DJ~ Ql~1AM~\t~ D\/\ lO\t'\~oJt, | -
----J:==--fJA-fl.~-~ | M l~-- | ~vt- c1.cflli' or ,._ hru.,{IN>-/,1,,t,, clu-K -
-----+-Q..u_ t: | r.l.Nrvv-1- fed lo | I M.o,.l~ efw, ,/Ud/~-
----+---11- | t-eJ. ,. · -~ ii\. | j,\ | BI iYV'e. 7 | 8vl: | ~ | · w1 | s~
----+-~~-"' fl) | J. &" | cl.M c..-c__ ' • . • .• •

~"en aa.tJt/il dflt'ii'fl a vc~fl tc fk., -Jt,,Qelt:,t

our oief\+lo-.\ tx f s,rff~,~ iVI to e.xisfin_,1 h«t!fkave
vis o \1' c fIX__

t


L

rt----~ J\A,1,_\ ~'J\O_ Ci\ l c1 \w- LL~-==

l:>~-5- lS_ "'--~aa-,L !-"'tJ,f ~..ul)\.,vt-<. _ 11&1r;hl ~t1--- r-- .. n...J.f- ~i / O'~ c.,.A.A,t'[.c ___ ~ - .

t-_ ___ .- -~us Jt.uJ -~ Y!Uf_ -~f- 1D __ '64:J~_,._1'tr~ (_~b01ft-r-
----- ~1k. ~ - o<,f ~ 0 Sf_1 __d r{~-~-t ?__


### ~- - 11~\-ui °"-\ ~rw--0i eds ro

b-t 5 O-.ri | CAncl V\J) \---1
,' .W °'-.S "X,d

/ --+·' -----


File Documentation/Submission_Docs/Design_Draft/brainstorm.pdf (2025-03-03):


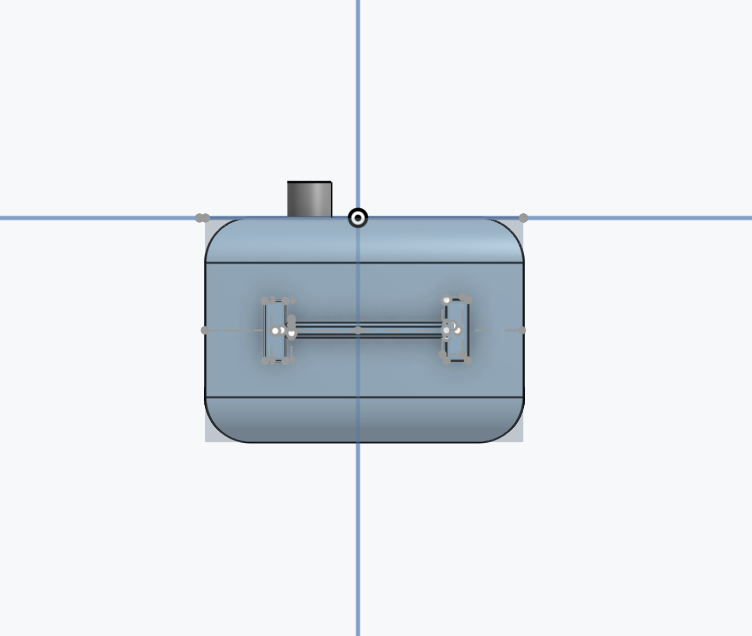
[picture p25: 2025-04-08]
Documentation/CAD Designs/hinge view 2.png

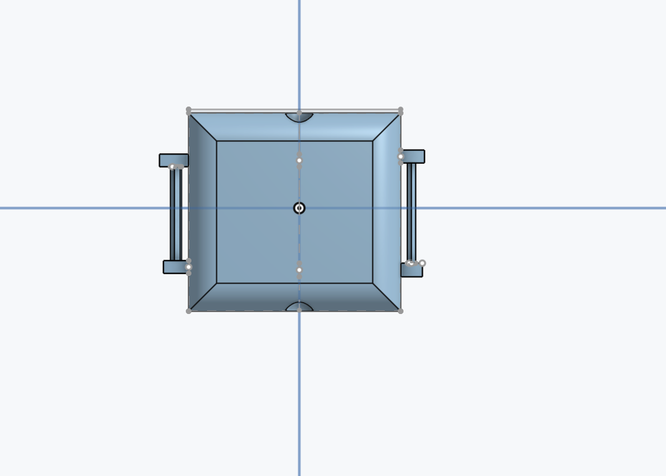
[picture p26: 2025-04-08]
Documentation/CAD Designs/front view 2.png

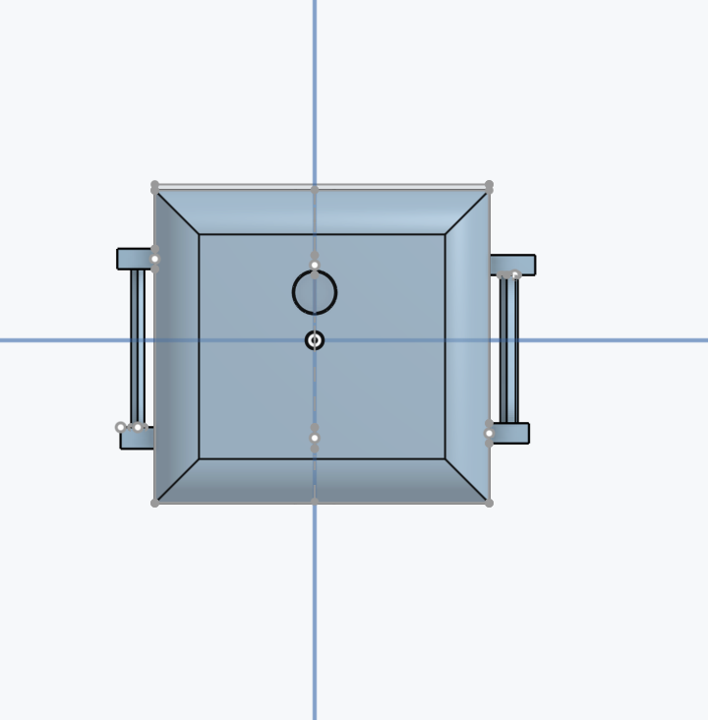
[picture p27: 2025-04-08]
Documentation/CAD Designs/bottom view 2.png

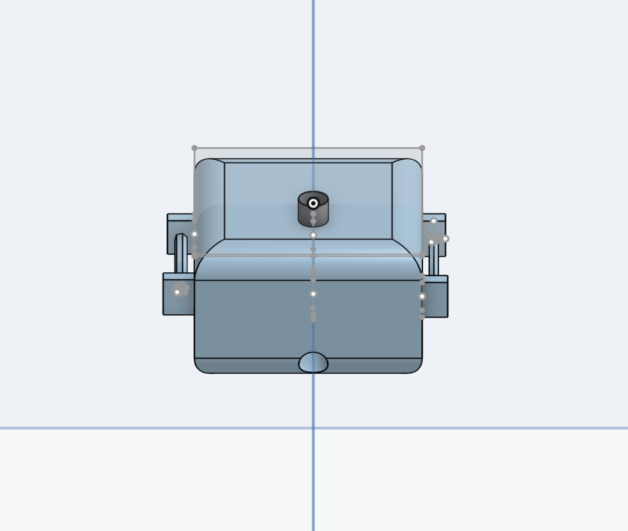
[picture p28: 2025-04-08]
Documentation/CAD Designs/side view 2.png

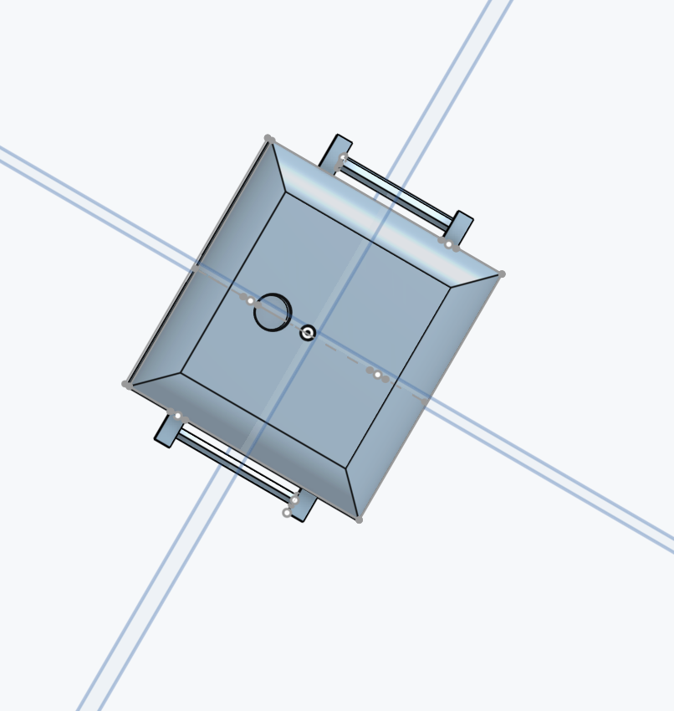
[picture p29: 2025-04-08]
Documentation/CAD Designs/omni proto 2.png

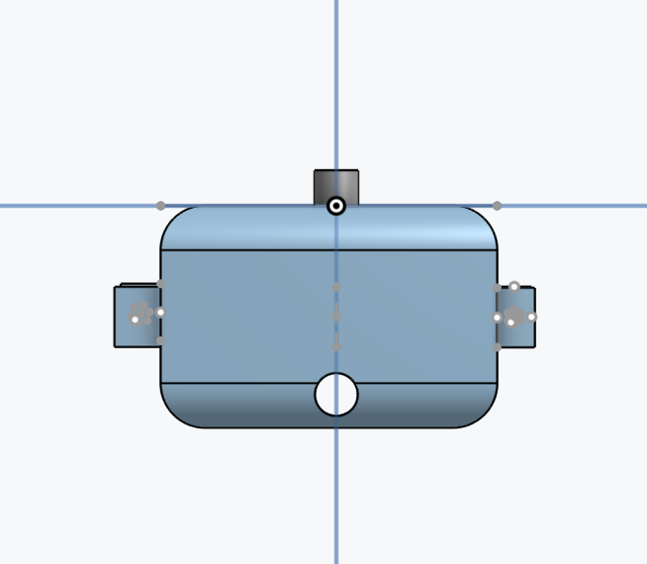
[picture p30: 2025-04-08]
Documentation/CAD Designs/other proto 2.png

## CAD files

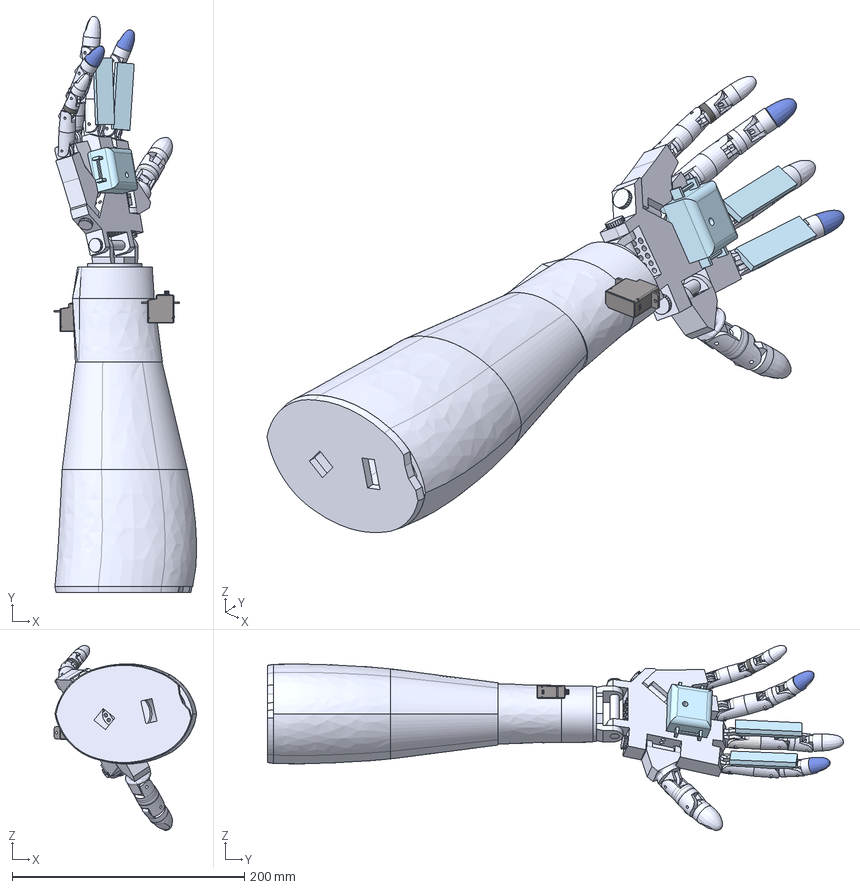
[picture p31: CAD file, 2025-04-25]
Documentation/CAD Designs/CAD Hand Prototype/TheraHand 4-24-25.step
122.7 x 495.9 x 159.4 mm
Forearm 2
Rotawrist 2
HS-53 x 2
WristlargeV4
Thumb
Forearm 1
Forearm cover
WristsmallV32
Screw 1
Screw 3
Screw 2
WristsmallV31
Falange 3-2(2)
Falange Ucu 2
Falange 3-5(2)
Falange 3-3(2)
Falange 3-4(2)
Falange 3-6(2)
Rotavrist3V2
Rotawrist1V1
Falange 3-4(3) x 2
Falange 3-6(3) x 2
Falange 3-5(3) x 2
Falange 3-2(3) x 2
Falange 3-3(3) x 2
Falange Ucu 3 x 2
Falange Ucu
Falange 3-2
Falange 3-5
Falange 3-4
Falange 3-6
Falange 3-3
Thumb1
Thumb3
Thumb5
Thumb4
Thumb6

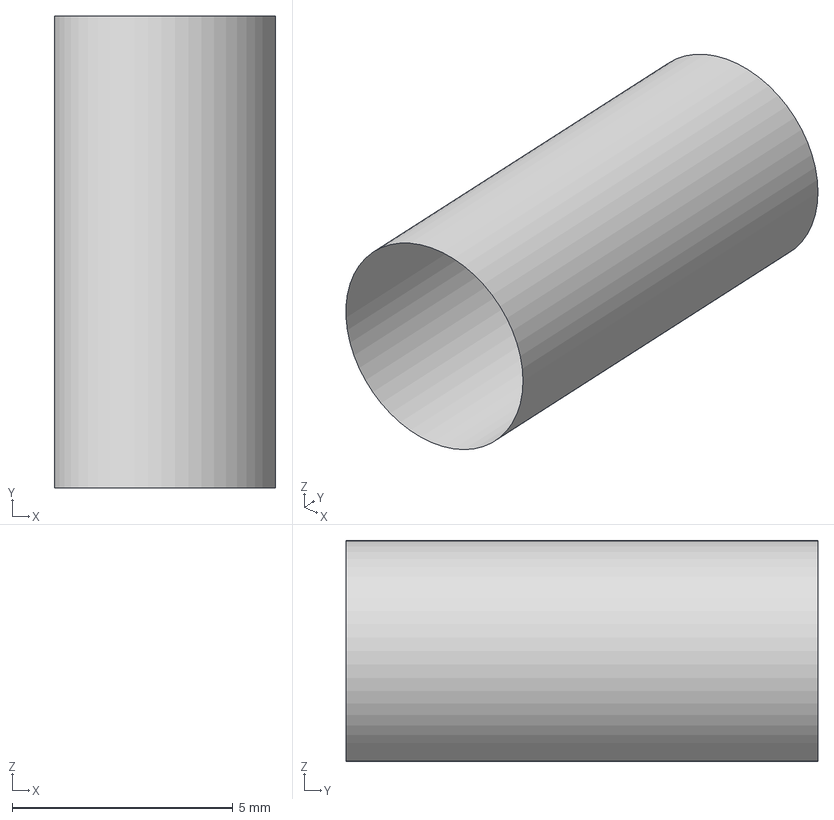
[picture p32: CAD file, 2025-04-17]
Documentation/CAD Designs/Servo Housing/CAD Servo Housing Extrusions 4-17-25.step
5.00 x 10.7 x 5.00 mm

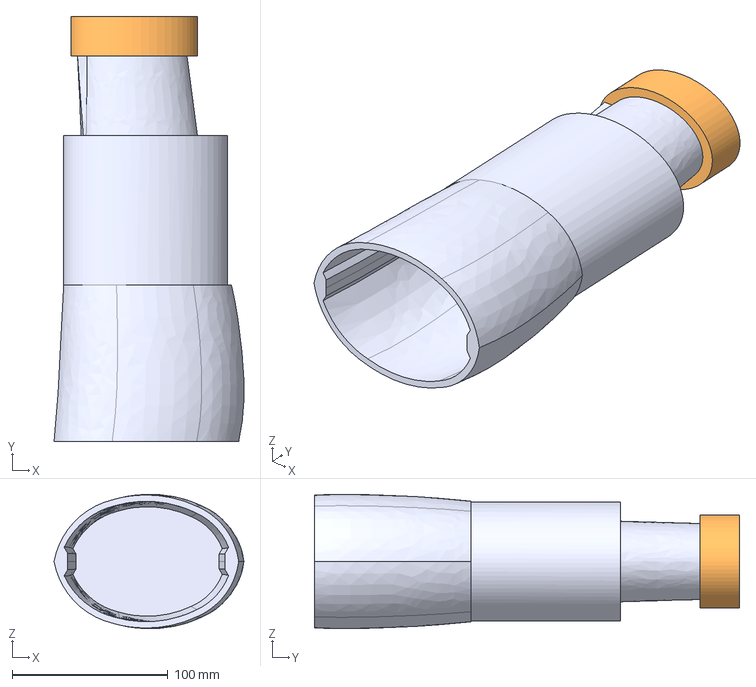
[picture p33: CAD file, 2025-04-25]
Documentation/CAD Designs/CAD Hand Prototype/Forearm Stand.step
122.0 x 273.0 x 86.2 mm

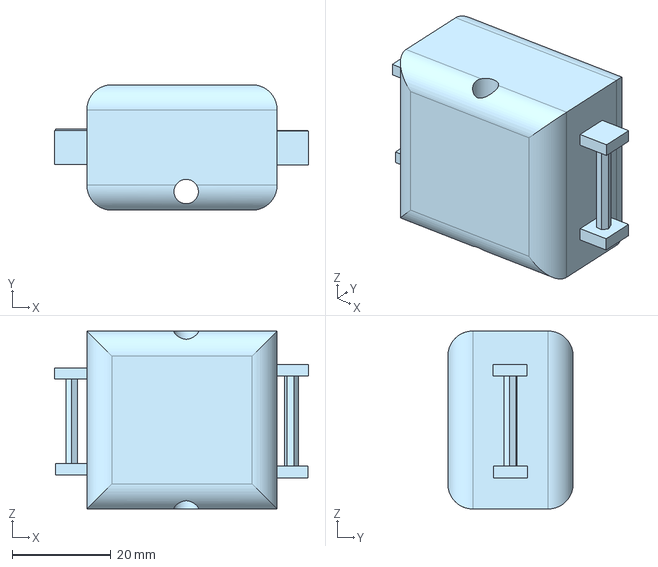
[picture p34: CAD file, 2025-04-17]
Documentation/CAD Designs/Servo Housing/CAD Servo Housing Body 4-17-25.step
51.4 x 25.4 x 36.0 mm

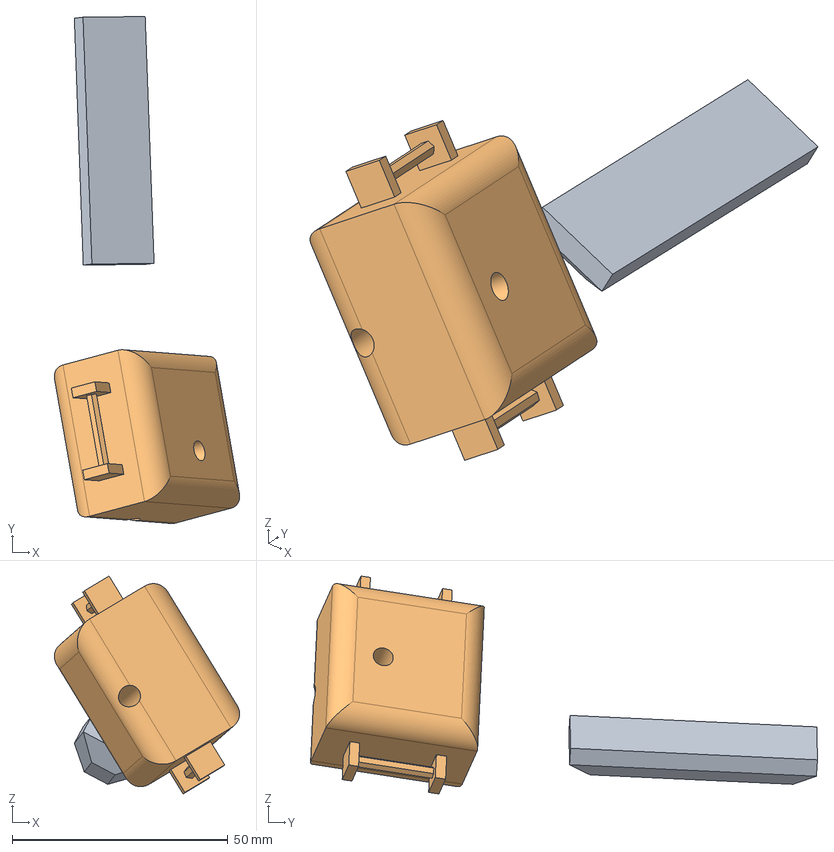
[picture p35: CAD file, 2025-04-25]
Documentation/CAD Designs/CAD Hand Prototype/flex sensor.step
43.0 x 117.6 x 50.5 mm

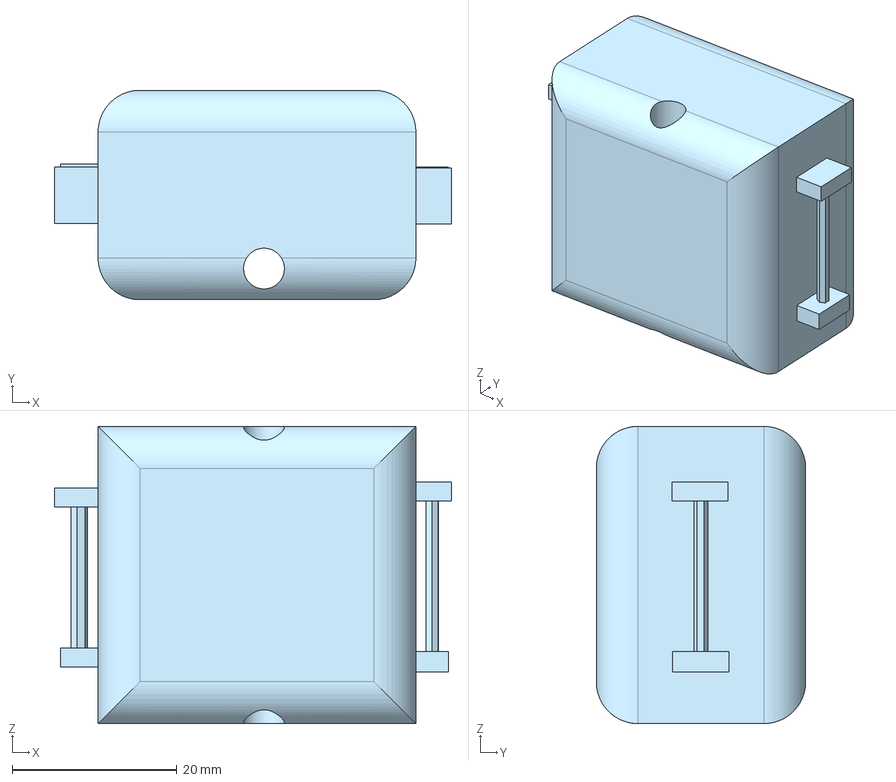
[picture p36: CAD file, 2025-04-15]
Documentation/CAD Designs/Servo Housing/CAD Servo Housing Body 4-15-25.step
48.1 x 25.4 x 36.0 mm

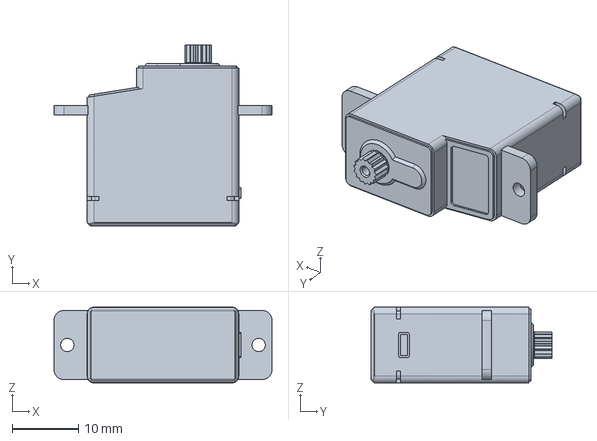
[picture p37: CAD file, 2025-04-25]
Documentation/CAD Designs/CAD Hand Prototype/Servo for hand.step
32.8 x 27.3 x 11.4 mm

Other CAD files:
Documentation/CAD Designs/slice/upper part stand.gcode.3mf
Documentation/CAD Designs/slice/printing 4-28-25.gcode.3mf
Documentation/CAD Designs/slice/Forearm 1.gcode.3mf
Documentation/CAD Designs/Servo Housing/CAD Servo Housing Extrusions 4-15-25.step
Documentation/CAD Designs/CAD Hand Prototype/wire housing component.step
Documentation/CAD Designs/Part Studio 1 - Part 1.x_t
Documentation/CAD Designs/Part Studio 1, Extrusions.x_t

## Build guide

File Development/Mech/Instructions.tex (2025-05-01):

\documentclass[conference]{IEEEtran}
\usepackage{graphicx}
\usepackage{url}
\usepackage{listings}
\usepackage{color}

\definecolor{codegray}{gray}{0.95}
\lstset{
  backgroundcolor=\color{codegray},
  basicstyle=\ttfamily\small,
  frame=single,
  breaklines=true,
  columns=fullflexible
}

\begin{document}

\title{Thera-Hand Mechanical Instructions}
\author{\IEEEauthorblockN{Andy Vo, Ethan Cesario, Aliyaa Islam}
\IEEEauthorblockA{Department of Computer Science and Engineering\\
University of California, Santa Cruz}}
\maketitle

\section{ESP32-C3 Setup Instructions}

This section describes how to configure the ESP32-C3 development board for use on a personal computer.

\subsection{Requirements}
\begin{itemize}
    \item ESP32-C3 development board
    \item USB-C cable
    \item Internet-enabled computer (Windows, Linux, or macOS)
    \item Git
    \item Python 3.7 or later
\end{itemize}

\subsection{Installation of Prerequisites}

\subsubsection{Python}
Download and install Python from \url{https://www.python.org/downloads/}. During installation, ensure the option to add Python to the system PATH is selected.

\subsubsection{Git}
Download Git from \url{https://git-scm.com/} and complete the installation using default settings.

\subsection{ESP-IDF Installation}

To install the official Espressif IoT Development Framework (ESP-IDF), execute the following commands:

\begin{lstlisting}
git clone --recursive https://github.com/espressif/esp-idf.git
cd esp-idf
\end{lstlisting}

Then run the install script:

\begin{itemize}
    \item Linux/macOS:
    \begin{lstlisting}
    ./install.sh
    \end{lstlisting}
    \item Windows:
    \begin{lstlisting}
    install.bat
    \end{lstlisting}
\end{itemize}

\subsection{Environment Setup}

Before building or flashing firmware, set up the environment as follows:

\begin{itemize}
    \item Linux/macOS:
    \begin{lstlisting}
    . ./export.sh
    \end{lstlisting}
    \item Windows:
    \begin{lstlisting}
    export.bat
    \end{lstlisting}
\end{itemize}

\subsection{Flashing and Testing}

Connect the ESP32-C3 board to the computer via USB. Identify the correct serial port:

\begin{itemize}
    \item Linux/macOS: \texttt{ls /dev/ttyUSB*} or \texttt{ls /dev/cu.*}
    \item Windows: Use Device Manager to find the COM port
\end{itemize}

Build and flash a project using:

\begin{lstlisting}
idf.py build
idf.py -p [PORT] flash
idf.py -p [PORT] monitor
\end{lstlisting}

Replace \texttt{[PORT]} with the detected port name.

\subsection{Troubleshooting}
\begin{itemize}
    \item Ensure drivers for USB-to-UART chips (e.g., CP210x, CH340) are installed.
    \item Use a data-capable USB cable.
    \item If the board does not respond, reset it using the \texttt{EN} button and retry.
\end{itemize}

\section{Wiring Instructions for Flex Sensors and Servos}

This section explains how to wire five flex sensors and two Smraza Micro Servo S51 motors to the ESP32-C3 using a breadboard. Refer to Fig.~\ref{fig:circuit} for a visual representation.

\subsection{Flex Sensor Connections}

Each of the five flex sensors is connected in a voltage divider configuration using a 10~k$\Omega$ pull-down resistor. The resulting analog voltage can be read by the ESP32-C3.

\begin{itemize}
    \item One end of each flex sensor connects to the 3.3~V power rail.
    \item The other end of each sensor connects to a GPIO pin and a 10~k$\Omega$ resistor.
    \item Each 10~k$\Omega$ resistor is connected to ground (GND).
    \item The junction between the sensor and resistor is connected to the ESP32-C3 ADC input pins as follows:
    \begin{itemize}
        \item Sensor 0 $\rightarrow$ GPIO0
        \item Sensor 1 $\rightarrow$ GPIO1
        \item Sensor 2 $\rightarrow$ GPIO2
        \item Sensor 3 $\rightarrow$ GPIO3
        \item Sensor 4 $\rightarrow$ GPIO4
    \end{itemize}
\end{itemize}

\subsection{Servo Motor Connections}

Two Smraza Micro Servo S51 motors are connected to the ESP32-C3:

\begin{itemize}
    \item \textbf{Power:} Connect the red (V\textsubscript{CC}) wire of each servo to the 5~V power rail.
    \item \textbf{Ground:} Connect the brown/black (GND) wire of each servo to the ground rail.
    \item \textbf{Signal:} Connect the yellow/white signal wires to the GPIO pins:
    \begin{itemize}
        \item Servo 0 $\rightarrow$ GPIO5
        \item Servo 1 $\rightarrow$ GPIO7
    \end{itemize}
\end{itemize}

\begin{figure}[!ht]
    \centering
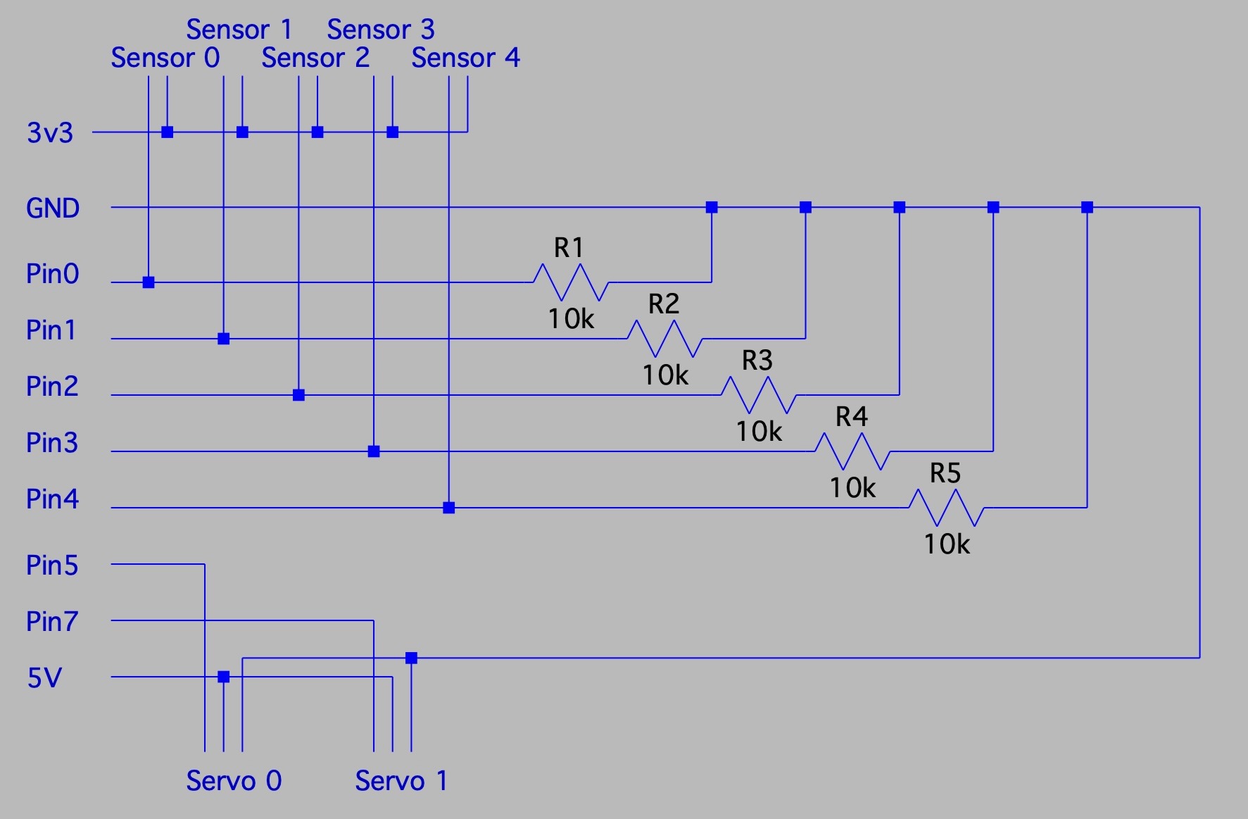
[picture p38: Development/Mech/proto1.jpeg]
    
    \caption{Circuit diagram showing ESP32-C3 wiring with 5 flex sensors and 2 Smraza Micro Servo S51 motors.}
    \label{fig:circuit}
\end{figure}

\section{Functional Testing and Calibration}

After wiring the ESP32-C3 with the flex sensors and servos as described in the previous section, functionality can be verified using two test scripts: one for the flex sensors and another for servo motion.

\subsection{Flex Sensor Data Capture}

A Python or C-based script is used to read the analog values from the ESP32-C3's ADC pins. These values are mapped linearly to a range of 0 to 100. Based on empirical testing, flex sensor states are interpreted as follows:

\begin{itemize}
    \item Values $\leq 40$: Sensor is bent \textbf{backwards}
    \item Values $> 40$: Sensor is bent \textbf{forwards}
\end{itemize}

These thresholds can be fine-tuned per sensor using calibration profiles stored in software.

\subsection{Servo Function Testing}

A separate script drives the two Smraza Micro Servo S51 motors through their full range of motion for two minutes. The test parameters are as follows:

\begin{itemize}
    \item \textbf{Waveform Generator:} Squarewave, 50~Hz frequency, 5~V\textsubscript{PP} (peak-to-peak)
    \item \textbf{Power Supply:} 4.8~V, 5~A
    \item \textbf{PWM Duty Cycle Calibration:}
    \begin{itemize}
        \item \textbf{2.3\% duty cycle:} Servo rotates fully to the \textbf{left}
        \item \textbf{12.4\% duty cycle:} Servo rotates fully to the \textbf{right}
    \end{itemize}
\end{itemize}

These values are used to validate the full operational range of the servo motors and ensure consistent response to PWM control signals.

\textit{Note: Although many hobby servos accept 3.3~V control signals, some may require signal level shifting to 5~V for reliable operation.}

\section{5V Power Supply and Continuous Servo Control}

To power two Parallax continuous rotation servos simultaneously, a regulated 5~V power supply is connected via a barrel jack interface. This setup provides adequate current and voltage stability to operate both servos under load.

\subsection{Barrel Jack Power Setup}

\begin{itemize}
    \item Use a 5~V DC power supply rated at a minimum of 2~A.
    \item Connect the positive terminal of the power supply to the barrel jack's center pin.
    \item Connect the ground terminal to the outer sleeve of the barrel jack.
    \item The barrel jack then connects to the breadboard's 5~V and GND rails.
    \item From the breadboard rails, connect power and ground to each Parallax servo as follows:
    \begin{itemize}
        \item Red wire (V\textsubscript{CC}) $\rightarrow$ 5~V rail
        \item Black wire (GND) $\rightarrow$ GND rail
        \item White wire (signal) $\rightarrow$ ESP32-C3 GPIO pin
    \end{itemize}
    \item Example GPIO assignments:
    \begin{itemize}
        \item Servo A $\rightarrow$ GPIO6
        \item Servo B $\rightarrow$ GPIO7
    \end{itemize}
\end{itemize}

\subsection{Servo Direction Test Program}

A test script is used to validate bidirectional rotation of both continuous rotation servos. The following logic is applied:

\begin{itemize}
    \item Rotate both servos clockwise for 20 seconds.
    \item Pause momentarily.
    \item Rotate both servos counter-clockwise for 20 seconds.
\end{itemize}

The direction of rotation is determined by the PWM duty cycle:

\begin{itemize}
    \item \textbf{Clockwise:} 1.3~ms pulse width (approximately 6.5\% duty at 50~Hz)
    \item \textbf{Counter-clockwise:} 1.7~ms pulse width (approximately 8.5\% duty at 50~Hz)
    \item \textbf{Stop (optional):} 1.5~ms pulse width (neutral)
\end{itemize}

An example pseudocode implementation:

\begin{lstlisting}
    // Pseudocode for testing Parallax servos
    setPWMFrequency(50);  // 50 Hz standard
    setPWMDuty(GPIO6, 6.5);  // Clockwise
    setPWMDuty(GPIO7, 6.5);
    delay(20000);  // 20 seconds

    setPWMDuty(GPIO6, 8.5);  // Counter-clockwise
    setPWMDuty(GPIO7, 8.5);
    delay(20000);  // 20 seconds

    // Optionally stop
    setPWMDuty(GPIO6, 7.5);
    setPWMDuty(GPIO7, 7.5);
\end{lstlisting}

\subsection{Safety Notes}
\begin{itemize}
    \item Always power the ESP32-C3 from a separate 3.3~V source or USB while driving high-current loads like servos from 5~V.
    \item Verify power supply ratings and ensure the total current draw does not exceed 5~A.
    \item Add a common ground between all components (ESP32, servos, sensors, and power supply).
\end{itemize}

\end{document}

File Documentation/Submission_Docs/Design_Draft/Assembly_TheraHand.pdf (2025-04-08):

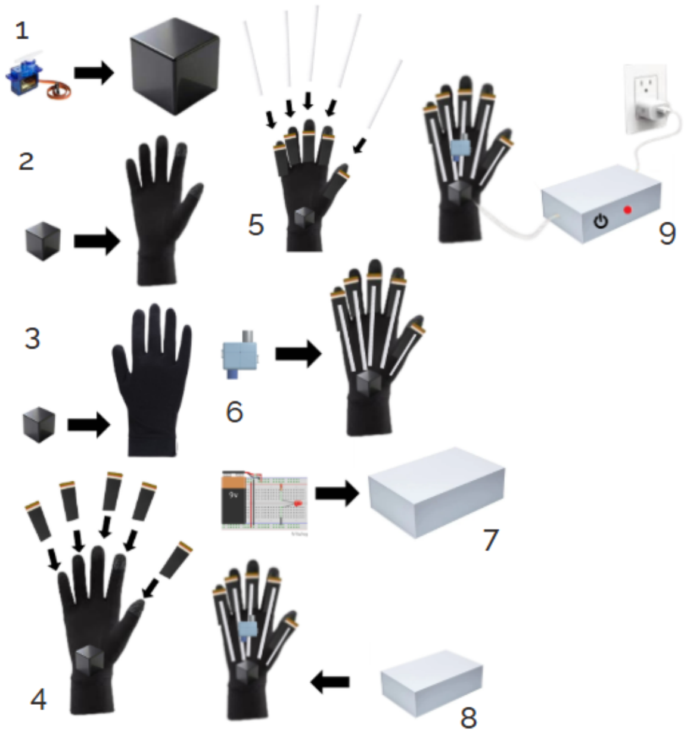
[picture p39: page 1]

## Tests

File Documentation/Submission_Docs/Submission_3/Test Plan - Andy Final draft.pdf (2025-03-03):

## Test 1

Full Range of motion on each finger - The device should be able to move in the full range of motion for each finger. Determine through flex sensor data in the amount of flexion (degrees).

Scope:

- System: Robotic/assistive hand device equipped with flex sensors
- Goal: To determine if each finger achieves its full range of motion
- Test Expectations (Hypothesis): The device should enable each finger to achieve range of motion within 5% error of an average human’s natural finger range. Administrative Details:
- Client/Organization: UCSC BSOE CSE123A&B
- Test Conductors: Research Team under Prof. David Harrison.
Design of Experiment:
- Type of test method: Controlled experiment using flex sensors to track finger flexion
- Significance: Ensures the device can replicate the expected movement range of human fingers.
Testing Apparatus & Equipment:
- Glove with integrated flex sensors
- Voltage divider circuit with known resistor (? ohms)
- Arduino
- Computer for data logging and visualization
Independent variable(s): Actuation movement signal sent to device. Dependent variable(s): Measured flexion angle (degrees) from flex sensors
Number of Factors: Single-factor (flexion range per finger)
Sampling Procedure:
- Sample Collection: Each finger tested individually through repeated movement cycles.
- Sample Size: Minimum of 30 repetitions per finger to ensure statistical validity.

Procedure:

1. Setup: Mount the device securely and ensure proper calibration of flex sensors.
2. Baseline Measurement: Record natural rest position of each finger.
3. Testing:
- Actuate each finger from full extension to full flexion.
- Record flex sensor data at key points of movement (0°, 45°, 90°, etc.).
- Repeat the process for each finger, ensuring consistency.
4. Safety Precautions:
- Ensure the device does not exceed mechanical limits to prevent damage.
- Wear protective gear when handling moving parts.
5. Data Collection:
- Data logged digitally via the DAQ system (laptop).
- Observations recorded manually for potential external influences.
6. Observation of External Factors:

- Ambient temperature variations.
- Device vibrations and mechanical inconsistencies.
- Any potential latency in response times.

Expected Outcomes:

- The device should demonstrate flexion within the expected biomechanical range (0°- 90° for DIP, 0°- 100° for PIP, 0°- 90° for MCP, depending on finger).
- Deviation beyond 2.5% of standard human range to be flagged for recalibration.
- If the device does not meet the expected range, adjustments in control algorithms and mechanical design may be necessary.

## Test 2

Ability to fit on a common hand - The device should be able to fit securely and comfortably on common hand sizes. Using straps for adjustability.

Scope:

- System Identified: Robotic/assistive hand device designed for human use with adjustable straps.
- Goal/Purpose: To determine if the device can fit securely and comfortably on common hand sizes.
- Parameters Defined: Fit assessment will be conducted based on security, comfort, and adjustability of the straps.
- Justification for Inclusion: Ensuring the device can be worn by a range of users with different normal hand sizes is critical for usability.
- Test Expectations (Hypothesis): The device should fit securely around the middle of the hand and forearm using adjustable straps, providing a snug but comfortable fit.

Administrative Details:

- Client/Organization: UCSC BSOE CSE123A&B
- Test Conductors: Research Team under Prof. David C. Harrison.

Design of Experiment:

- Type of Testing Method: Physical fit testing using standardized hand models.
- Significance: Ensures that the device can accommodate a range of hand sizes.

Test Apparatus & Equipment:

- Robotic/assistive hand device with straps for adjustability.
- 3D hand model (male/female).

- Measuring tools for assessing gaps and pressure points (ruler, measuring tape, etc.).
- User feedback for qualitative comfortability assessment

Variables Identified:

- Independent Variable: Strap tension and hand size.
- Dependent Variable: Fit security, pressure distribution, and comfort level

Number of Factors Considered: Two-factor (strap-adjustability and hand size variations)

Sampling Procedure:

- Sample Collection: Fit tested on different hand models.
- Sample Size: Two hand sizes tested (male and female 3D models), three trials per size

Procedure:

### 1. Setup:

- Prepare the hand models and device with adjustable straps.
- Ensure straps are at their default adjustment before each trial.

### 2. Baseline Measurement:

- Measure the circumference of each hand model at the middle of the hand and forearm.

### 3. Testing:

- Place the device on each hand model and secure it using the straps.
- Adjust the straps for a snug but comfortable fit.
- Record strap tension using measuring tape and pressure sensors.
- Conduct subjective assessment for comfort and stability.

### 4. Safety Precautions:

- Ensure straps do not exert excessive pressure that could restrict circulation.
- Confirm that the device does not cause discomfort or excessive movement restrictions.

### 5. Data Collection:

- Quantitative data: Strap tightness, pressure distribution, and movement stability.
- Qualitative data: User comfort feedback (1-10 scale).

### 6. Observation of External Factors:

- Impact of movement on strap security.
- Any noticeable discomfort due to prolonged wear.

Expected Outcomes:

- The device should securely fit common hand sizes without excessive gaps or pressure points.
- The adjustable straps should allow for a customized fit without discomfort.
- If fit issues arise, modifications to strap length, padding, or buckle placement may be necessary.

## Test 3

Durability of the device - The device should have enough structural integrity to survive repeated usage and external forces.

Scope:

- System Identified: Robotic/assistive hand device.
- Goal/Purpose: To determine the durability and structural integrity of the device under repeated usage and external forces.
- Parameters Defined: Durability will be assessed based on mechanical wear, structural integrity, and functional performance over time.
- Justification for Inclusion: Ensuring the device maintains function and structural integrity over extended use is critical for reliability and user safety.
- Test Expectations (Hypothesis): The device should withstand repeated flexion cycles, external forces, and environmental conditions without significant performance degradation.

Administrative Details:

- Client/Organization: UCSC BSOE CSE123A&B.
- Test Conductors: Research Team under Prof. David C. Harrison.

Design of Experiment:

- Type of Testing Method: Accelerated life testing, mechanical stress testing, and environmental exposure testing.
- Significance: Ensures device longevity and reliability in real-world usage scenarios.

Test Apparatus & Equipment:

- Robotic/assistive hand device.
- Mechanical testing rig for repeated flexion cycles.
- Load cell sensors to measure stress and strain.
- Environmental chamber for temperature and humidity variations.
- Impact testing apparatus for drop and shock resistance.

Variables Identified:

- Independent Variable: Number of flexion cycles, applied force, environmental conditions.
- Dependent Variable: Structural integrity, material wear, loss of functionality.

Number of Factors Considered: Three-factor (mechanical fatigue, impact resistance, environmental durability).

Sampling Procedure:

- Sample Collection: Multiple devices subjected to different stress conditions.
- Sample Size: Minimum of 5 units per test condition.

Procedure:

1. Setup:
- Mount the device on a mechanical testing rig.
- Calibrate sensors to measure force, stress, and performance degradation.
2. Baseline Measurement:
- Record initial material integrity and functionality metrics.
3. Testing:
- Mechanical Fatigue Test:
- Subject each finger mechanism to repeated flexion cycles (minimum 100,000 cycles).
- Monitor for signs of wear, stiffness, or failure.
- Impact Resistance Test:
- Drop the device from various heights onto different surfaces.
- Assess structural damage and continued operability.
- Environmental Durability Test:
- Expose the device to temperature fluctuations (-10°C to 50°C) and high humidity.
- Evaluate material degradation and operational stability.
4. Safety Precautions:
- Ensure testing rig prevents unintended hazards.
- Use protective barriers during impact testing.
5. Data Collection:
- Quantitative data: Wear analysis, force measurements, failure rates.
- Qualitative data: Observations of material degradation and user-reported durability issues.
6. Observation of External Factors:
- Effects of prolonged use on mechanical performance.
- Environmental factors leading to premature material failure.

Expected Outcomes:

- The device should maintain functional integrity for at least 100,000 flexion cycles without significant degradation.
- The structural components should withstand typical impact forces without catastrophic failure.
- Environmental exposure should not lead to material breakdown or loss of functionality.
- If durability issues arise, material selection, mechanical design, or protective coatings may need revision.

Date & Location for Testing:

| Name(s): | Date: | Location:

Test 1: Full Range of Motion on each finger

Test 2: Ability to fit on common hand

Test 3: Device Durability

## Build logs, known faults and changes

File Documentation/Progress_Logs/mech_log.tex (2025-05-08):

\documentclass[12pt]{article}
\usepackage[margin=1in]{geometry}
\usepackage{fancyhdr}
\usepackage{titlesec}

\setlength{\headheight}{15.0pt}
\pagestyle{fancy}
\fancyhf{}
\lhead{Thera-Hand Project}
\rfoot{\thepage}

\titleformat{\section}{\normalfont\Large\bfseries}{\thesection}{1em}{}
\begin{document}

\begin{center}
    {\Huge\bfseries Mech Log}
\end{center}
\vspace{1em}
\hrule
\vspace{1em}

\section*{Instructions}
To make a new log entry, copy and paste the block below:

\begin{verbatim}
\section*{YYYY-MM-DD}
[Write a description of what was done. Be concise but specific.]

\vspace{1em}
\noindent\textit{Contributor: Your Name}
\vspace{1em}
\hrule
\end{verbatim}

\vspace{1em}
\hrule
\vspace{1em}

% Example log entries below

\section*{2025-04-10}
Typed meeting notes from the meeting with the professor and shared it with the group. Added to the bill of materials and shared it with the professor. Discussed goals with the mech team such as finalizing the design and made issues for them.

Found new hand model that would be more flexible than the current wooden one. The current wooden one is too stiff and would not work well for testing the device.
Looked for different servo motors with Ethan and Andy. Goal was to look for one with more power that would be able to move a finger since the current one is too weak.

\vspace{1em}
\noindent\textit{Contributor: Aliyaa Islam}
\vspace{1em}

Attended meeting with professor. Worked on bill of materials with Aliyaa and Andy. Worked on acquiring bill of materials from lab and theorizing most needed parts. Compared and found usable servos, along with the best hand models needed. Found that rigid hand models will be more realistic and better for a prototype than a completely elastic hand model.

In actual therapy hands may be really rigid and thus a higher power and 360 degree servo may be needed and was chosen. A duplicate servo was chosen that was even higher power but harder to use was also chosen.

Organized the mechanical group with Ethan, Aliyaa and Andy. Set milestones that needed to be achieved which were displayed in issues.

\vspace{1em}
\noindent\textit{Contributor: Ethan Cesario}
\vspace{1em}
\hrule

% Add new entries below this line

\section*{2025-04-15}
Worked on flex sensor data reading in terminal. Figured out how to connect esp32c3 micro controller to laptop.

\vspace{1em}
\noindent\textit{Contributor: Andy Vo}
\vspace{1em}

Worked with Aliyaa and Andy on connecting the flex sensor to a usable computer. Built a basic resistor divider to convert the resistance read off of the flex sensor to be able to read voltage. Worked with Aliyaa and Andy to make a basic C script which was loaded onto the ESP32C3 to read flex sensor data. Worked with group members to find the best time for the tutor. Strategized more deadlines needed for mechanical side of project.

Worked with Akash to assign basic CAD milestones along with theorizing specific servo placements.

\vspace{1em}
\noindent\textit{Contributor: Ethan Cesario}
\vspace{1em}

\hrule

\section*{2025-04-16}
We worked on fixing flex sensor data by making the program output 10x as fast as before. Also set the range of the flex sensor detection to 0-100 degrees. We set it to where below 40 degrees is when the flex sensor is bent backwards. Anything above 40 is forward contraction of the finger. We plan to find how accurate our numbers are later.

We set the program to stop at 2 min as estimation for how long 1 exercise cycle would take. We then tracked the flex sensor data and logged the data into a file called log.txt. Fixed outliers with data recorded while also recording a much larger data set and averaging them out.

Added Akash onto the mechanical group. Assigned more work to Akash and worked on CAD model for individual finger with Akash. Including drawings.
Added more parts to bill of materials including glue types, added multiple glove types. One being rigid and the other being more flexible. Decided to go with glove design due to connectivity issues occurring with flex sensor.

Worked with Andy to find another hand model, and also ordered metal wiring, will be used to compare against ability to fishing wire. We also ordered 2 different servos to test out which is best strength and saftey-wise.

\vspace{1em}
\noindent\textit{Contributor: Andy Vo, Aliyaa Islam, Ethan Cesario}
\vspace{1em}
\hrule

\section*{2025-04-17}
We worked on expanding data reading to 5 flex sensors at a time. This was done by replicating the wiring for the flex sensor 5 times over and connecting them to different GPIO pins on the ESP32C3. We also modified the C script to assign the new GPIO pins into the respective flex sensors and organized output data to display each flex sensor respectively. Got LEDs to help with debugging with output detection. We also plan to use LEDs to test turning the device on and off.

We did some testing to make sure each flex sensor was being read correctly based on the bend.

Andy and Ethan worked on getting Smraza mico-servos S51 to run based on the following parameters:
The waveform generator is set to a squarewave 50 Hz, 5 VPP. Power supply is at 4.8V 5 Amps. We figured out that a duty cycle of 12.4 percent is the far right and 2.3 percent is the far left. 

\vspace{1em}
\noindent\textit{Contributor: Andy Vo, Aliyaa Islam, Ethan Cesario}
\vspace{1em}

Found command to be able to save data into a text document for every run. Edited code so that it runs for 2 minutes (theoretical run time for exercises).

\vspace{1em}
\noindent\textit{Contributor: Aliyaa Islam}
\vspace{1em}

\hrule

\section*{2025-04-22}

\vspace{1em}
Setup basic servo movements with a timing schedule. Created code that ran servo through ESP32C3 board. Fixed timing schedule of servo and made it run on a finite loop. Fixed breadboard simplifying wiring and increasing functionality, added color coded wiring for the flex sensors and fixed outliers in resistors. Added servo capability into breadboard with color coded wiring. Connected second servo to breadboard and sourced parts from BELS. Adapted code to be able to run second servo. Fixed voltage issues with second servo and identified and faulty servo.

\vspace{1em}

\vspace{1em}
\noindent\textit{Contributor: Aliyaa Islam, Ethan Cesario, Andy Vo}
\vspace{1em}

Worked with Akash to iron down wrist/forearm design. Made sketches for Akash for forearm attachment and servo placements on attachment.

\vspace{1em}
\noindent\textit{Contributor: Ethan Cesario, Akash}
\vspace{1em}
\hrule

\section*{2025-04-23}
Tested servos functionality and got parts for external power source. Current parts didn't work and looked for substitutes asking other group for any tips and progress they made.

\vspace{1em}
\noindent\textit{Contributor: Andy Vo, Ethan Cesario}
\vspace{1em}
\hrule

\section*{2025-04-24}
Created the Instruction manual for mechanical side. Added instructions for setting up ESP32C3 board. Also added wiring diagram for 5 flex sensors and 2 servos to instruction manual.
Put down testing for functionality of flex sensor data capture and servos functionality.

\vspace{1em}
\noindent\textit{Contributor: Andy Vo, Ethan Cesario}
\vspace{1em}
\hrule

\section*{2025-04-29}
Got new servos and tested their functionality. Used barrel jack and attached to power supply for servos power. We wrote C code for continuous rotation servos so that it would rotate clockwise and counter clockwise for 20 seconds. Tested differing exercises along with a failed attempt to change exercises through terminal while flashed to board. Settled on trying to not test other exercises through terminal but to test them through sending full code.

\vspace{1em}

Got delivery from BELS. Including both servos and detached power bank for remote power. Got a barrel jack adapter for detached power bank. Got a separate barrel jack adapter that fits the bread board and that can be usable. Had issues finding barrel jack adapter documentation and how to properly implement it into the breadboard.

\vspace{1em}

Tested both new servos accounting for strength, power, and rotation. Thought about differing exercises including time, speed and actuation. Adapted over servo code to work with new servos. Settled on the continuous rotation servo due to its ease of code and lower power consumption. Other servo that we ordered was too powerful for use and could be a danger to not only use but could also damage other parts due to strength. Adapted new tests along with thinking of backups in case parts are not delivered in time. Added proper wiring to breadboard for implementing new servos along with detached power source.

\vspace{1em}

Worked with Caden over hurdle concerning flex sensor data and hand needed for online hand model. Attended meeting with Charles talking about progress and next steps including servos and what we expect still needs to be done. Set a new schedule for what needs to be accomplished over the following two weeks and must be done deadlines.

\vspace{1em}
\noindent\textit{Contributor: Andy Vo, Ethan Cesario}
\vspace{1em}
\hrule

\section*{2025-04-22}
Worked on making multiple possible exercises, trying to figure out how to prompt the user to choose between them. Was difficult as the ESP32c3 can't detect selection from the terminal.  
Tried getting PuTTY but process would become too complicated for the user. Then tried to make selection via Esp32c3 buttons, but realized there were only two, so cycling through isn't ideal either.
\vspace{1em}
\noindent\textit{Contributor: Aliyaa Islam}
\vspace{1em}
\hrule

\section*{2025-04-23}
Worked on different settings for the servo motors. Wanted the exersize to continue for 20 seconds to test the servo rotations. 

Worked on programming an exersize. 
\vspace{1em}
\noindent\textit{Contributor: Aliyaa Islam}
\vspace{1em}
\hrule

\section*{2025-04-24}
Exercise was running fine for a clench and unrest cycle. Was difficult trying to get it to rotate slowly since the servo picks up speed and rotates to its maximum speed. Tried multiple different things but speed didn't seem to change much.
\vspace{1em}
\noindent\textit{Contributor: Aliyaa Islam}
\vspace{1em}
\hrule

\section*{2025-04-28}
Continued to work on making the servos slower. Solution was to make the duration of the spin shorter. This way the exersize finished before the servo is able to pick up its speed. Also works since the exersize is only supposed to be a slight clench of their fingers, so the more advanced exersizes (full clench) might be more difficult. 
\vspace{1em}
\noindent\textit{Contributor: Aliyaa Islam}
\vspace{1em}
\hrule

\section*{2025-04-29}
The servo spins enough to get the finger mostly clenched. Will assemble and see how it works once more parts arrive. 
Worked on combining the servo and accuator strip code.
\vspace{1em}
\noindent\textit{Contributor: Aliyaa Islam}
\vspace{1em}
\hrule

\section*{2025-04-30}
Worked on assembling materials together and fixing code. 
\vspace{1em}
\noindent\textit{Contributor: Aliyaa Islam}
\vspace{1em}
\hrule

\end{document}

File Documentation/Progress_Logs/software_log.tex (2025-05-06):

\documentclass[12pt]{article}
\usepackage[margin=1in]{geometry}
\usepackage{fancyhdr}
\usepackage{titlesec}

\pagestyle{fancy}
\fancyhf{}
\lhead{Thera-Hand Project}
\rfoot{\thepage}

\titleformat{\section}{\normalfont\Large\bfseries}{\thesection}{1em}{}
\begin{document}

\begin{center}
    {\Huge\bfseries App Log}
\end{center}
\vspace{1em}
\hrule
\vspace{1em}

\section*{Instructions}
To make a new log entry, copy and paste the block below:

\begin{verbatim}
\section*{YYYY-MM-DD}
[Write a description of what was done. Be concise but specific.]

\vspace{1em}
\noindent\textit{Contributors: Your Name}
\vspace{1em}
\hrule
\end{verbatim}

\vspace{1em}
\hrule
\vspace{1em}

% Example log entries below

\section*{2025-04-10}
Caden developed Thera-App v0.1 with foundational UI and navigation. Jhovanny integrated firebase authentication and database setup. Testing needed for ESP32 connectivity and data handling.

\vspace{1em}
\noindent\textit{Contributors: Caden, Jhovanny}
\vspace{1em}
\hrule

% Add new entries below this line
\section*{2025-04-15}
Established a TA meeting time (Wednesdays 1:10pm). Further development of app frontend while pending mech team's design. Firebase is set up. Jhovanny is working on the backend to ensure data flow from the app to the database. Caden is focusing on UI/UX improvements based on initial feedback.
Akash is 3D printing the new hand wiring device. Jhovanny and Akash communicated about future 3D printing model concepts.

\vspace{1em}
\noindent\textit{Contributors: Caden, Jhovanny}
\vspace{1em}
\hrule

\section*{2025-04-16}
Had first TA meeting with Charlie. Discussed the app's current state and future goals. Caden presented the app's UI/UX design, and Jhovanny explained the backend setup. Charlie provided feedback on the design and suggested improvements for user engagement. Akash shared updates on the 3D printing process and discussed potential challenges with the mech team.
Caden and Jhovanny are working on implementing Charlie's feedback into the app. 

\vspace{1em}
\noindent\textit{Contributors: Caden, Jhovanny}
\vspace{1em}
\hrule

\section*{2025-04-17}
Held standup meeting with Professor Harrison. Discussed progress and potential app updates for user experience. Looking to integrate the app with the mech team's design via wireless cloud communication. Caden and Jhovanny are working on the app's full stack to ensure smooth data flow. Akash is finalizing the 3D printing model for the hand wiring device.

\vspace{1em}
\noindent\textit{Contributors: Caden, Jhovanny}
\vspace{1em}
\hrule

\section*{2025-04-22}
Jhovanny worked toward wireless communication between esp32 and firestore database. Made updates. Trying to figure out wifi connectivity as eduroam proved to be too difficult. Working toward firestore data collection by next meeting

\vspace{1em}
\noindent\textit{Contributors: Jhovanny}
\vspace{1em}
\hrule

\section*{2025-04-23}
Jhovanny is working toward achieving succesful wireless communication between esp32 and firestore db. Wifi is established using eduroam mobile broadcast on local windows device. Issue found with uploading session data. Fails to open connection using CA certification. Working toward completion for professor standup meeting.
Jhovanny met with TA. TA helped achieve wifi connection. Jhovanny is working toward achieving succesful wireless communication between esp32 and firestore db. Wifi is established using eduroam mobile broadcast on local windows device. Issue found with uploading session data. Fails to open connection using CA certification. Working toward completion for professor standup meeting.
Caden is developing app's isometric model integration as well as user authentication and professional/client view screens. 

\vspace{1em}
\noindent\textit{Contributors: Jhovanny}
\vspace{1em}
\hrule

%test credential push for Rpi4 setup
\section*{2025-04-24}
Jhovanny worked on esp32c3 wireless connectivity. Firestore db was dropped in favor of developing local server to host cloud storage. Server setup was successful and stored in Thera-app directory along with Docker container and setup instructions. esp main directory cleaned up unnecessary files. ESP to local server information sending was successful. Data is stored in "cloud" server in json arrays for each session.
Next time, aiming to work on integrating servo information and possibly setting up remote server onto a raspberry pi for demo purposes. Need to look into getting app to retrieve cloud information and display on app.

Also want to integrate bluetooth functionality for local connection to the machine. 
List for app updates:
- User ID setup and authentication
- Professional view screen
- Client view screen
- Isometric model integration
- Bluetooth connection to machine
- Cloud data retrieval and display
- Analytics & History Screens
- Exercise Tracking and Modification

\vspace{1em}
\noindent\textit{Contributors: Jhovanny}
\vspace{1em}
\hrule

\section*{2025-04-28}
Jhovanny modified and deployed cloud to a Raspberry Pi 4 model to function remotely upon bootup. Did extensive testing using Ngrok tunneling to figure out remote connectivity without using eduroam but was unsuccessful. Rpi4 functions as a local "cloud" server to send data. Need to implement API excslusion to allow for remote access.
Caden succesfully integrated isometric hand model into app. Also integrated user authentication. 
Akash printed new 3D model for the hand wiring device.

Future tasks:
Need to figure out bluetooth connectivity
Getting web app communicating with cloud server
Completing professional and client view screens
Getting analytics and history screens up and running
Simulating real data flow from Machine->Cloud->App and App->Cloud->Machine

\vspace{1em}
\noindent\textit{Contributors: Jhovanny}
\vspace{1em}
\hrule

\section*{2025-04-29}
Met with Charles TA and discussed team progress. Jhovanny presented current state of the cloud on Rpi4. Charles advised using AWS to host cloud services.
Jhovanny then proceeded to set up AWS account and deploy cloud server. Successfully deployed cloud server on AWS and achieved ESP32 connectivity to AWS. Data is represented in JSON format and stored in AWS EC2 instance.
Caden presented app updates. He integrated user authentication and isometric model. He also worked on the professional and client view screens. Caden is working on the analytics and history screens.

\vspace{1em}
\noindent\textit{Contributors: Jhovanny}
\vspace{1em}
\hrule

\section*{2025-04-30}
Met with Charles TA and discussed team progress. Jhovanny presented current state of the cloud on AWS. Charles advised using AWS to host cloud services.
Jhovanny is working on setting up connectivity between AWS and the app to ensure data flow. He is also working on the API to allow for remote access to the cloud server.

Caden presenteed app updates. User authentication is functional. 

\vspace{1em}
\noindent\textit{Contributors: Jhovanny}
\vspace{1em}
\hrule

\end{document}

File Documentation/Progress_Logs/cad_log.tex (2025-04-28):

\documentclass[12pt]{article}
\usepackage[margin=1in]{geometry}
\usepackage{fancyhdr}
\usepackage{titlesec}

\setlength{\headheight}{15.0pt}
\pagestyle{fancy}
\fancyhf{}
\lhead{Thera-Hand Project}
\rfoot{\thepage}

\titleformat{\section}{\normalfont\Large\bfseries}{\thesection}{1em}{}
\begin{document}

\begin{center}
    {\Huge\bfseries CAD Log}
\end{center}
\vspace{1em}
\hrule
\vspace{1em}

\section*{Instructions}
To make a new log entry, copy and paste the block below:

\begin{verbatim}
\section*{YYYY-MM-DD}
[Write a description of what was done. Be concise but specific.]

\vspace{1em}
\noindent\textit{Contributor: Your Name}
\vspace{1em}
\hrule
\end{verbatim}

\vspace{1em}
\hrule
\vspace{1em}

\section*{2025-04-10}
Refined the prototype presented in final presentations in CSE123A. Had issues with the hinges being too weak, strengthened them by thickening and turning them into hexagons as well as increasing the length of the attachments. Reattached extrusion on top and adjusted dimensions

\vspace{1em}
\noindent\textit{Contributor: Akash Srinivasan}
\vspace{1em}
\hrule

\section*{2025-04-11}
[Began work on a 3D hand model of our functional prototype]
\vspace{1em}
\noindent\textit{Contributor: Akash Srinivasan}
\vspace{1em}
\hrule

\section*{2025-04-15}
[Successfully found and imported a suitable hand model from GrabCAD (https://grabcad.com/library/robotic-hand-inmoov-inspired-1). Had issues with importing the file and the maneuvering took a few hours. Designed a few parts of my own in Assembly]
\vspace{1em}
\noindent\textit{Contributor: Akash Srinivasan}
\vspace{1em}
\hrule

\section*{2025-04-16}
[Grafted designs onto the imported hand model (flex sensors, wire housing, and servos). Began work on other aspects of functional prototype, such as power bank/supply and other potential versions of the prototype (support plate)]
\vspace{1em}
\noindent\textit{Contributor: Akash Srinivasan}
\vspace{1em}
\hrule

\section*{2025-04-17}
[Met with professor, showed him functional prototype model. Got good feedback on it]
\vspace{1em}
\noindent\textit{Contributor: Akash Srinivasan}
\vspace{1em}
\hrule

\section*{2025-04-21}
[Worked with group on what further CAD designs and prints are needed for our functional prototype to successfully work. Came to the conclusion that a stand (like a forearm) will be needed for our model hand as well as housing of sorts for the servos to sit and operate within]
\vspace{1em}
\noindent\textit{Contributor: Akash Srinivasan}
\vspace{1em}
\hrule

\section*{2025-04-22}
[Began work on hand model stand. Took measurements to make it as accurate as possible]
\vspace{1em}
\noindent\textit{Contributor: Akash Srinivasan}
\vspace{1em}
\hrule

\section*{2025-04-23}
[Finished Work on Forearm Stand. Used an import and modified it to add different sections that I needed]
\vspace{1em}
\noindent\textit{Contributor: Akash Srinivasan}
\vspace{1em}
\hrule

\section*{2025-04-24}
[Met with professor, gave good feedback on Forearm Stand. Work on that is complete until the hand model arrives so I can get the exact specs. Professor wants me to update the hand model prototype, superimposing or importing a GLTF file into my pre-existing one.]
\vspace{1em}
\noindent\textit{Contributor: Akash Srinivasan}
\vspace{1em}
\hrule

\section*{2025-04-25}
[Began work on the servo housing unit...]
\vspace{1em}
\noindent\textit{Contributor: Akash Srinivasan}
\vspace{1em}
\hrule

\section*{2025-04-28}
[Printed one component, sliced the rest. Will have to solder two pieces together as they are too big for one printer. Finished prototyping servo housing unit.]
\vspace{1em}
\noindent\textit{Contributor: Akash Srinivasan}
\vspace{1em}
\hrule

\end{document}

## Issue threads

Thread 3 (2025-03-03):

Submission 3

jhovuribe, 2025-03-03:
Submission 3. Requires the following components:

Submit the following as sections in a single PDF document:

Design for Manufacture and Assembly
Ethics Statement
Budget for Prototype
Life Cycle Assessment
Test Plan
Updates to information already submitted

alnislam, 2025-03-03:
[Adobe Scan Mar 2, 2025.pdf](https://github.com/user-attachments/files/19061268/Adobe.Scan.Mar.2.2025.pdf)
DMA sketch progress on #3 Aliyaa

Closed 2025-03-05.

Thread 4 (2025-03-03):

Draft Design Document

jhovuribe, 2025-03-03:
Combine information created / submitted so far into a single document that you'll add to during the Spring Quarter.

Remember all sections are woks in progress; your test plan, for example, does not need to be complete, it just needs to show progress since last submitted.

Cover Page
Front Matter
Executive Summary
Ethics Statement
Table of Contents
Body
Background
Personas
Problem Definition
Need & Goal Statements
Design Objectives
Concepts Considered
Conceptualizations
Brain Storming Output
Concept Selection
Decision Table
Detail of Design (majority of the document)
Free format description of design
Include diagrams, schematics, wire-frames, etc.
Be reasonably detailed but remember this is not yet complete
Economic Analysis
Design for Manufacture & Assembly
Life Cycle Assessment
Outstanding Issues
Appendices
Models and Simulations
Decision Table Inputs
Test Plan
Test Results

Closed 2025-04-08.

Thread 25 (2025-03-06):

Submission 3: Test Plan

Andurdur, 2025-03-06:
9 Tests for correct device functionality and overall build

Closed 2025-03-06.

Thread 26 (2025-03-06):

Submission 3: Test Plans

Andurdur, 2025-03-06:
9 tests for correct device functionality and overall build

Closed 2025-03-06.

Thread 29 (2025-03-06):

3D print model for palm compartment box

Andurdur, 2025-03-06:
Using CAD to design 3D model for palm compartment to contain wire and string. Will 3D print as well.

Closed 2025-04-10.

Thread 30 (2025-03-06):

Flex Sensor Calibration

Andurdur, 2025-03-06:
Integrate Flex sensor output values from ESP/Arduino GPIO pins.

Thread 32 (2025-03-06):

Servos Calibration & deciding appropriate servos for Device

Andurdur, 2025-03-06:
Figuring out what how to get servos working and deciding best servos to use for the rehabilitation device.

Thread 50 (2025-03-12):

Draft Design Document - DMA Fixes

jhovuribe, 2025-03-12:
Edit and enhance draft design document contents

Closed 2025-04-08.

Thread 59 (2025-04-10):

3D Hand Wireframe App Model

jhovuribe, 2025-04-10:
Wireframe Representation of Hand Movements on Web Application

cadenroberts, 2025-04-28:
Hand has been benchmarked with an array of joint values that can be changed.

Closed 2025-04-28.

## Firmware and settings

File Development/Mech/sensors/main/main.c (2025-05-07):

#include <stdio.h>
#include <math.h>
#include <string.h>
#include <inttypes.h>
#include <time.h>

#include "freertos/FreeRTOS.h"
#include "freertos/task.h"
#include "driver/adc.h"
#include "esp_log.h"
#include "esp_wifi.h"
#include "esp_event.h"
#include "nvs_flash.h"
#include "esp_netif.h"
#include "esp_http_client.h"
#include "cJSON.h"
#include "esp_sntp.h"  // Added for time sync

#define WIFI_SSID "Jho"
#define WIFI_PASS "12345678"
#define CLIENT_ID "ethan"
#define API_KEY   "THERAethan_cred_2025"
#define SERVER_URL "https://35.215.126.127/" 

//UPDATE: moved to Google Cloud: static IP address - https://35.215.126.127/ (therahand.info) -> DOMAIN NAME

#define FLEX_CHANNEL ADC_CHANNEL_0
#define FLEX_WIDTH ADC_WIDTH_BIT_12
#define SAMPLE_COUNT 10
#define SAMPLE_INTERVAL_MS 50
#define MAX_DURATION_MS 10000
#define MAX_SAMPLES (MAX_DURATION_MS / SAMPLE_INTERVAL_MS)

static float voltage_array[MAX_SAMPLES];
static float flex_array[MAX_SAMPLES];
static int sample_idx = 0;

void initialize_sntp(void) {
    ESP_LOGI("SNTP", "Initializing SNTP");
    sntp_setoperatingmode(SNTP_OPMODE_POLL);
    sntp_setservername(0, "pool.ntp.org");
    sntp_init();
}

bool obtain_time(void) {
    initialize_sntp();

    time_t now = 0;
    struct tm timeinfo = { 0 };
    int retry = 0;
    const int retry_count = 10;

    while (timeinfo.tm_year < (2023 - 1900) && ++retry < retry_count) {
        ESP_LOGI("SNTP", "Waiting for system time... (%d/%d)", retry, retry_count);
        vTaskDelay(2000 / portTICK_PERIOD_MS);
        time(&now);
        localtime_r(&now, &timeinfo);
    }

    if (timeinfo.tm_year < (2023 - 1900)) {
        ESP_LOGE("SNTP", "Failed to get time over NTP.");
        return false;
    }

    ESP_LOGI("SNTP", "Time obtained successfully.");
    return true;
}

static bool wifi_init_sta(void) {
    esp_netif_init();
    esp_event_loop_create_default();
    esp_netif_create_default_wifi_sta();

    wifi_init_config_t cfg = WIFI_INIT_CONFIG_DEFAULT();
    esp_wifi_init(&cfg);

    wifi_config_t wifi_config = {
        .sta = {
            .ssid = WIFI_SSID,
            .password = WIFI_PASS,
        },
    };

    esp_wifi_set_mode(WIFI_MODE_STA);
    esp_wifi_set_config(WIFI_IF_STA, &wifi_config);
    esp_wifi_start();

    ESP_LOGI("WIFI", "Connecting to %s...", WIFI_SSID);
    esp_wifi_connect();

    for (int i = 0; i < 10; ++i) {
        wifi_ap_record_t ap_info;
        vTaskDelay(pdMS_TO_TICKS(500));
        if (esp_wifi_sta_get_ap_info(&ap_info) == ESP_OK) {
            ESP_LOGI("WIFI", "Connected to AP: %s", ap_info.ssid);
            return true;
        }
    }

    ESP_LOGE("WIFI", "Failed to connect to Wi-Fi after retries");
    return false;
}

static void send_data_to_server(void) {
    time_t now;
    time(&now);
    char timestamp[32];
    snprintf(timestamp, sizeof(timestamp), "%" PRId64, (int64_t)now);

    cJSON *root = cJSON_CreateObject();
    cJSON_AddItemToObject(root, "voltages", cJSON_CreateFloatArray(voltage_array, sample_idx));
    cJSON_AddItemToObject(root, "flex_percent", cJSON_CreateFloatArray(flex_array, sample_idx));

    char url[256];
    snprintf(url, sizeof(url), SERVER_URL "/upload/%s/%s", CLIENT_ID, timestamp);
    char *post_data = cJSON_Print(root);

    ESP_LOGI("HTTP", "Posting to: %s\n%s", url, post_data);

    esp_http_client_config_t config = {
        .url = url,
        .method = HTTP_METHOD_POST,
    };

    esp_http_client_handle_t client = esp_http_client_init(&config);
    esp_http_client_set_header(client, "Content-Type", "application/json");
    esp_http_client_set_header(client, "X-API-KEY", API_KEY);
    esp_http_client_set_post_field(client, post_data, strlen(post_data));

    esp_err_t err = esp_http_client_perform(client);
    if (err == ESP_OK) {
        ESP_LOGI("HTTP", "Status = %d, content_length = %" PRId64,
                 esp_http_client_get_status_code(client),
                 (int64_t)esp_http_client_get_content_length(client));
    } else {
        ESP_LOGE("HTTP", "HTTP POST failed: %s", esp_err_to_name(err));
    }

    esp_http_client_cleanup(client);
    cJSON_Delete(root);
    free(post_data);
}

void app_main(void) {
    nvs_flash_init();

    if (!wifi_init_sta()) {
        ESP_LOGE("MAIN", "Wi-Fi connection failed. Halting program.");
        return;
    }

    if (!obtain_time()) {
        ESP_LOGE("MAIN", "Failed to obtain time. Halting program.");
        return;
    }

    adc1_config_width(FLEX_WIDTH);
    adc1_config_channel_atten(FLEX_CHANNEL, ADC_ATTEN_DB_11);

    const float min_voltage = 0.25f;
    const float max_voltage = 1.2f;
    float readings[SAMPLE_COUNT] = {0};

    int sample_index = 0;
    int elapsed_ms = 0;

    while (elapsed_ms < MAX_DURATION_MS && sample_idx < MAX_SAMPLES) {
        int raw = adc1_get_raw(FLEX_CHANNEL);
        float voltage = (raw / 4095.0f) * 3.3f;
        readings[sample_index++] = voltage;

        if (sample_index >= SAMPLE_COUNT) {
            float sum = 0.0f;
            for (int i = 0; i < SAMPLE_COUNT; i++) sum += readings[i];
            float mean = sum / SAMPLE_COUNT;

            float variance = 0.0f;
            for (int i = 0; i < SAMPLE_COUNT; i++) variance += powf(readings[i] - mean, 2);
            float std_dev = sqrtf(variance / SAMPLE_COUNT);

            float filtered_sum = 0.0f;
            int count = 0;
            for (int i = 0; i < SAMPLE_COUNT; i++) {
                if (fabsf(readings[i] - mean) <= std_dev) {
                    filtered_sum += readings[i];
                    count++;
                }
            }

            float avg_voltage = (count > 0) ? filtered_sum / count : mean;
            float flex_percent = 0.0f;
            if (avg_voltage >= min_voltage) {
                flex_percent = ((avg_voltage - min_voltage) / (max_voltage - min_voltage)) * 100.0f;
                if (flex_percent > 100.0f) flex_percent = 100.0f;
            }

            voltage_array[sample_idx] = avg_voltage;
            flex_array[sample_idx] = flex_percent;
            sample_idx++;

            ESP_LOGI("FLEX", "Avg Voltage: %.3f V | Flex: %.1f%%", avg_voltage, flex_percent);
            sample_index = 0;
        }

        vTaskDelay(pdMS_TO_TICKS(SAMPLE_INTERVAL_MS));
        elapsed_ms += SAMPLE_INTERVAL_MS;
    }

    ESP_LOGI("FLEX", "Finished collecting. Uploading...");
    send_data_to_server();
}

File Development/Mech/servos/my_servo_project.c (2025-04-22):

#include <stdio.h>
#include "freertos/FreeRTOS.h"
#include "freertos/task.h"
#include "driver/ledc.h"
#include "esp_timer.h"

#define SERVO1_GPIO      5
#define SERVO2_GPIO      7
#define SERVO_PWM_FREQ   50
#define SERVO_PWM_RES    LEDC_TIMER_13_BIT
#define SERVO1_CHANNEL   LEDC_CHANNEL_0
#define SERVO2_CHANNEL   LEDC_CHANNEL_1

uint32_t percent_to_duty(float percent) {
    return (uint32_t)((percent / 100.0) * ((1 << 13) - 1));
}

void setup_servo(int gpio, ledc_channel_t channel) {
    ledc_channel_config_t channel_conf = {
        .gpio_num   = gpio,
        .speed_mode = LEDC_LOW_SPEED_MODE,
        .channel    = channel,
        .timer_sel  = LEDC_TIMER_0,
        .duty       = 0,
        .hpoint     = 0
    };
    ledc_channel_config(&channel_conf);
}

void set_servo_position(ledc_channel_t channel, float percent) {
    ledc_set_duty(LEDC_LOW_SPEED_MODE, channel, percent_to_duty(percent));
    ledc_update_duty(LEDC_LOW_SPEED_MODE, channel);
}

void app_main(void) {
    // Set up the timer
    ledc_timer_config_t timer_conf = {
        .speed_mode       = LEDC_LOW_SPEED_MODE,
        .duty_resolution  = SERVO_PWM_RES,
        .timer_num        = LEDC_TIMER_0,
        .freq_hz          = SERVO_PWM_FREQ,
        .clk_cfg          = LEDC_AUTO_CLK
    };
    ledc_timer_config(&timer_conf);

    // Set up both servos
    setup_servo(SERVO1_GPIO, SERVO1_CHANNEL);
    setup_servo(SERVO2_GPIO, SERVO2_CHANNEL);

    int64_t start_time = esp_timer_get_time();  // Microseconds

    while (esp_timer_get_time() - start_time < 20000000) {  // 20 seconds
        // Flex (closed)
        set_servo_position(SERVO1_CHANNEL, 12.4);
        set_servo_position(SERVO2_CHANNEL, 12.4);
        vTaskDelay(pdMS_TO_TICKS(1000));

        // Extend (open)
        set_servo_position(SERVO1_CHANNEL, 2.3);
        set_servo_position(SERVO2_CHANNEL, 2.3);
        vTaskDelay(pdMS_TO_TICKS(1000));
    }

    // Stop PWM after 20 seconds
    ledc_stop(LEDC_LOW_SPEED_MODE, SERVO1_CHANNEL, 0);
    ledc_stop(LEDC_LOW_SPEED_MODE, SERVO2_CHANNEL, 0);
}

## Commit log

2025-02-21 Email Chain PDFs
2025-03-03 DMA Push - progress on #3
2025-03-03 test finger flex progress on #3
2025-03-03 Add files via upload
    DMA sketch progress on #3 Aliyaa
2025-03-03 test durability of device and proofread test plans progress on #3
2025-03-04 DMA sketch progress on #3 Aliyaa
2025-03-04 Create CAD Designs
2025-03-04 CAD Designs #3
2025-03-04 CAD PARASOLID files, Progress on #3
    [Part Studio 1 - Part 1.x_t, Part Studio 1, Extrusions.x_t]
2025-03-04 Manufacture/Assembly Design - Progress on #3
2025-03-11 Update main.tex
    insert previous work from 1,2,3
2025-03-13 updated as of 3/13/25
    [Gantt Chart 3:13:25.csv]
2025-03-15 Update and rename Gantt Chart 3:13:25.csv to Gantt_Chart_3-13-25.csv
    Fixed naming
    [Gantt_Chart_3-13-25.csv]
2025-03-15 Prototype 2
2025-04-15 Cad mv
    [Part Studio 1 - Part 1.x_t, Part Studio 1, Extrusions.x_t]
2025-04-15 Servo component housing body
    [CAD Servo Housing Body 4-15-25.step]
2025-04-15 Servo component housing extrusion
    [CAD Servo Housing Extrusions 4-15-25.step]
2025-04-15 Create Flex_sensor_V1
    working C code flex sensor for esp32c3
2025-04-16 build removal staged
2025-04-17 Update main.c
    updated flex sensor code
    range 0-100
    runs for 2 mins
    runs faster
    [main.c]
2025-04-17 added log.txt file for output of flex sensors
2025-04-17 Update log.txt
    data for updated flex sensor code
2025-04-17 logged flex sensor progress as well as reformatted document
2025-04-17 logged flex sensor progress for 4/16/25
2025-04-17 Update mech_log.tex
    Added resistor divider section 4/15 Ethan
2025-04-17 Update mech_log.tex
    Updated BOM section and glove design in 4/16 Ethan
2025-04-17 Updated prototype
    [CAD Servo Housing Body 4-17-25.step]
2025-04-17 progress on getting 5 flex sensor reading
2025-04-17 test logging for flex sensors
2025-04-17 added servos progress for mini servos
2025-04-17 Logged change in flex sensor readings
2025-04-18 Flex sensor data description update
2025-04-18 LED reading logs
2025-04-20 Update mech_log.tex
    esp32c3 set up
2025-04-22 cloud staging build update
    [partitions.csv]
2025-04-22 servo
    code for two servo motors that runs for 20 seconds pulsing rotation
2025-04-22 added servos code directory
2025-04-23 Created CAD Log
2025-04-23 Update Thera-Hand CAD Log.tex
2025-04-24 Update mech_log.tex
    Servo 4/22
2025-04-24 Update mech_log.tex
    Fixed 4/17 servo
2025-04-24 Update mech_log.tex
    Servo timing schedule 4/22
2025-04-24 Update mech_log.tex
    Colorcoding servo breadboard.
2025-04-24 Update mech_log.tex
    Color code for flex sensor and outliers
2025-04-24 Update mech_log.tex
    Part sourcing and second servo breadboard.
2025-04-24 Update mech_log.tex
    Second servo in servo code
2025-04-24 Update mech_log.tex
    Second servo issue
2025-04-24 Update mech_log.tex
    Akash forearm attachment
2025-04-24 as of 4/24/25
    [TheraHand 4-24-25.step]
2025-04-24 added wiring instructions for flex and servos for prototype
2025-04-24 added testing for flex sensor functionality
2025-04-24 added testing for servos functionality
2025-04-24 logged instruction esp32c3
2025-04-24 logged instruction wiring
2025-04-25 mv design draft into sub docs
    [Gantt_Chart_3-13-25.csv]
2025-04-28 Progress on #thera_app
    fixed exercise and finger buttons, as well as list and table rending
2025-04-28 slice of forearm stand
    [Forearm 1.gcode.3mf]
2025-04-28 wire housing slice
    [printing 4-28-25.gcode.3mf]
2025-04-28 upper stand slice
    [upper part stand.gcode.3mf]
2025-04-30 progress on #thera_app
    Added the ability for doctors (authenticated and role checked) to add new patient accounts for themselves.
2025-04-30 progress on #thera_app
    added ability for doctors (role based access and authenticated) to create new patients for themselves
2025-04-30 Update Home.jsx
    large UI changes, doctor/patient view, messaging, add a user
2025-04-30 Update mech_log.tex
    Servos 4/29
2025-04-30 Update mech_log.tex
    servo testing 4/29
2025-04-30 Update mech_log.tex
    Servo decision 4/29
2025-04-30 Update mech_log.tex
    Continuous servo 4/29
2025-04-30 Update mech_log.tex
    Decision to not use other servo.
2025-04-30 Update mech_log.tex
    Flex sensor data issue 4/29
2025-04-30 Update mech_log.tex
    Power source 4/29
2025-05-01 added notes for servos testing
2025-05-04 complete create/delete patient, create/delete doctor, cascade
2025-05-06 Create servo_exersize_1
